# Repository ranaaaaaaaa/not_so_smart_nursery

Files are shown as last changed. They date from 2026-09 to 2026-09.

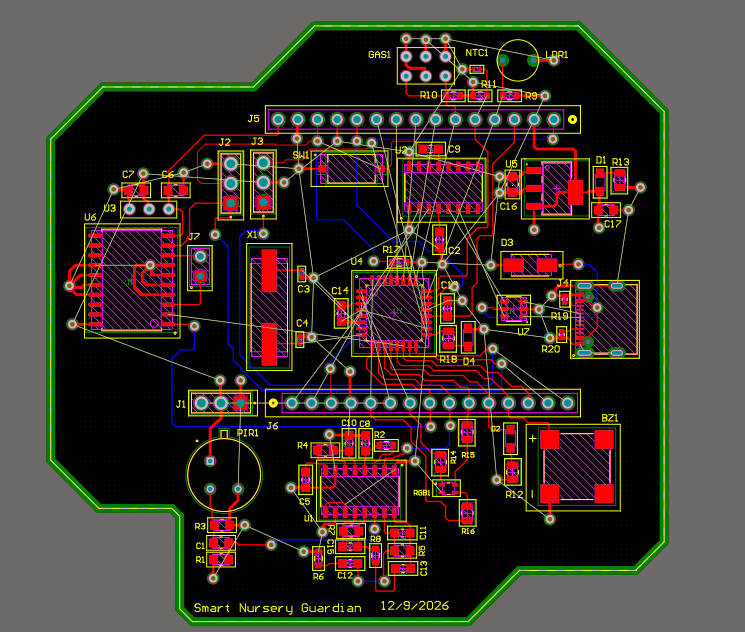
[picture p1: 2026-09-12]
Screenshot 2026-09-13 015350.png

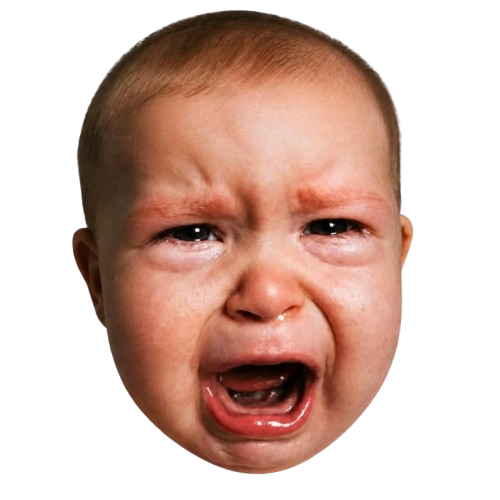
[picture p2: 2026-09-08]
3ayoota.png

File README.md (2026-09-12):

# not_so_smart_nursery

> drive:
https://drive.google.com/drive/folders/12p2iuLTkDaTgLdKXVU6b1ozY8I97_jF5

> tinkercad:[
https://www.tinkercad.com/things/jVpQvmCroje-copy-of-smart-nursery-guardian](https://www.tinkercad.com/things/jVpQvmCroje-copy-of-smart-nursery-guardian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)

# System Logic & Flow Overview

An AI-assisted embedded monitoring system that listens for infant cries, classifies their cause with a trained ML model, and coordinates a microcontroller to soothe, alert, and regulate the nursery environment in real time.

## 1. Architecture
The system is split across two devices that talk over a serial connection:

| Part | Runs On | Responsibility |
|---|---|---|
| **Python App (Tkinter GUI)** | Laptop | Microphone capture, noise reduction, VAD, ML cry classification, GUI display, video playback, Telegram alerts |
| **Firmware** | Microcontroller | Reads PIR, light (LDR), temperature (NTC), and gas sensors; drives servo, buzzer, RGB LED, lamp LED, and cooling fan; relays sensor events to the laptop |

**Key asymmetry:** audio never crosses the serial link - the laptop reads its own microphone directly, so cry detection and servo response have effectively zero latency. Every other sensor (motion, light, temperature, gas) is read by the microcontroller and relayed to the laptop over serial, so those messages are kept minimal to avoid flooding the link.

## 1.1 Servo Rocking Cycle (Actual Firmware Behavior)

While `cry == 1`, the servo repeats a fixed 4-second, 4-position cycle (not a simple back-and-forth between two angles):

| Time in cycle | Angle |
|---|---|
| 0–1s | 90° |
| 1–2s | 0° |
| 2–3s | 180° |
| 3–4s | 0° |

The cycle then restarts from 0°. As soon as `cry == 0`, the cycle timer resets and the servo stops advancing through positions.

## 2. Startup Sequence

1. **Microcontroller powers on** → initializes PIR, light, temperature, and gas sensors.
2. **Python app launches** → loads the pre-trained model (`already_trained_model.pkl`) once, opens the serial connection, and initializes the audio stream (PyAudio, 16 kHz, 1024-sample chunks).
3. **Tkinter GUI opens** in a calm/idle state and starts three independent polling loops via `window.after()`:
   - `update_gui` — reads serial data every 500 ms
   - `update_state` — evaluates `baby_state` every 500 ms and drives servo/video
   - `update_suggestion` — refreshes the on-screen suggestion text every 500 ms
   - The audio `read_stream` loop runs continuously (effectively every ~23 ms, gated by the mic buffer)

## 3. Live Audio Path (Cry Detection & Classification)

This is the core, time-critical loop and it runs on **two timescales at once**:

### 3.1 Fast path — every 1024-sample chunk (~64 ms), servo/VAD only
- Read a chunk from the mic.
- Normalize amplitude to `[-1, 1]`.
- If peak amplitude < 0.15 → treat as silence → **stop rocking** (`cry('C0')`).
- Otherwise → **start rocking** (`cry('C1')`) immediately.
- This gives the servo an instant reaction with no dependency on the ML model.

### 3.2 Slow path — every 6-second rolling window, ML classification
- Each chunk is also appended to a rolling buffer (`deque`, max 96,000 samples = 6 s @ 16 kHz).
- Once the buffer fills:
  1. Apply **spectral noise reduction** (`noisereduce`).
  2. Run **voice activity detection** via amplitude gating + `librosa.effects.split`.
  3. Extract a fixed-size feature vector: MFCC mean/std (13 coefficients each), F0 mean/std, RMS intensity mean/std, and duration.
  4. Feed the vector into the saved model → predicts `hungry`, `tired`, or `discomfort`.
  5. If the window was silent, `baby_state` resets to `"fine"`.
  6. The buffer then slides forward by 16,000 samples (1 second), so classification re-runs roughly once per second on overlapping windows.

```mermaid
flowchart TD
    A[Mic chunk arrives, 1024 samples] --> B{Peak amplitude < 0.15?}
    B -->|Yes| C[Send cry-stop to servo C0]
    B -->|No| D[Send cry-start to servo C1]
    C --> E[Push samples into 6s rolling buffer]
    D --> E
    E --> F{Buffer full<br/>96,000 samples?}
    F -->|No| G[Update waveform bars, wait next chunk]
    F -->|Yes| H[Noise reduction + VAD]
    H --> I{Sound present?}
    I -->|No| J[baby_state = fine]
    I -->|Yes| K[Extract MFCC / F0 / RMS / duration]
    K --> L[Run trained model]
    L --> M[baby_state = hungry / tired / discomfort]
    J --> N[Slide buffer forward 1s]
    M --> N
    N --> G
```

## 4. Response Logic by Classified State

Once `baby_state` is set, it drives GUI text, suggestions, servo/video, and buzzer via three independent 500ms loops:

| State | GUI Label | Suggestion | Extra Action |
|---|---|---|---|
| `hungry` | "YOUR BABY IS hungry" | "Consider feeding your baby." | Plays calming video **only if** gas level ≤ 500 (safe) |
| `tired` | "YOUR BABY IS tired" | "URGENT! Your baby requires your care right now." | Sends `B1` to buzzer over serial |
| `discomfort` | "YOUR BABY IS discomfort" | "Consider checking diaper, clothing, position." | — |
| `fine` | "YOUR BABY IS fine" | "NO suggestions." | Closes video window if open; sends `B0` (buzzer off) |

Note: the video and buzzer are **mutually exclusive with each other's triggers** — any state other than `hungry` closes the video window, and only `tired` keeps the buzzer active.

A **DISMISS** button lets a caregiver manually clear the displayed state to "fine" without waiting for the model.

## 5. Microcontroller-Side Sensor Logic

While the laptop handles audio, the microcontroller independently manages four sensor-driven behaviors every cycle:

### 5.1 Motion (PIR) → "Baby Awake"
- The PIR pin is sampled **once per second** (not continuously) within an 8-second window.
- Each `HIGH` reading increments a counter.
- If the counter reaches **4** before the 8 seconds elapse ⇒ `awake = 1`, and the window/counter reset immediately to start a fresh 8-second cycle.
- If 8 seconds elapse without reaching 4 ⇒ counter resets to 0 and `awake = 0` for that cycle.
- This means "4 motions in 8 seconds" is really "4 of up to 8 one-second samples," which filters out a single passing hand or a blanket shift while still catching sustained movement.
- Reported to the laptop over serial as `Awake:1` / `Awake:0`.

### 5.2 Room Lighting (LDR + LED)
The lamp LED turns on only when **both** are true:
- The LDR reading is **≥ 500** (this is the raw condition in firmware — confirm on your specific wiring/voltage-divider orientation whether a higher analog reading corresponds to a darker or brighter room, since LDR circuits can be wired either way), **AND**
- Baby is awake (from PIR) **OR** a cry is currently active (`cry == 1`, set by the laptop's fast VAD path over serial).

This is the one actuator that depends on **both** local sensor data and a laptop signal — everything else on the microcontroller (fan, status light) is fully local.

### 5.3 Temperature → Fan Speed + Status Color
| Range | Status Light | Fan |
|---|---|---|
| Below 25°C | Blue | Off (PWM 0) |
| 25°C – 30°C | Green | Half speed (PWM 127) |
| Above 30°C | Red | Full speed (PWM 255) |

Color and fan speed are derived from the same reading, so they always agree. Temperature is computed from the analog pin as `((analogRead * 5/1024) - 0.5) * 100` — a linear 10 mV/°C-with-0.5V-offset formula (common for analog temperature ICs; if you're actually using a raw NTC thermistor rather than a linear sensor, this formula would need to be replaced with a proper thermistor/Steinhart-Hart conversion, since NTC resistance isn't linear with temperature).

### 5.4 Gas/Smoke → Safety Alert (Highest Priority)
- Threshold: gas value **> 500**.
- **Buzzer logic on the microcontroller** is actually a combined OR: it sounds if gas exceeds the threshold, *or* if the laptop has sent `B1` (tired-cry alert) — either condition alone drives the buzzer HIGH. Both silence the buzzer via `B0`/gas dropping below threshold.
- The Python side additionally shows a full-screen red alert (`trigger_alert.py`) and plays an alert sound (`mashkal.mp3` via `playsound3`) and an image (`5atar.png`) when gas is detected.
- A **Telegram message** ("SERIOUS ALERT! CHECK ON YOUR BABY RIGHT NOW!") is sent via a direct HTTPS GET to the Telegram Bot API (`telegram_bot.py`).
- Any active calming video is immediately closed — the safety alert takes precedence.
- Alert window closes automatically once gas value drops back to ≤ 500.

```mermaid
flowchart TD
    G1[Gas reading] --> G2{Gas > 500?}
    G2 -->|Yes, alert not yet shown| G3[Trigger full-screen alert]
    G3 --> G4[Sound buzzer continuously]
    G4 --> G5[Send Telegram message]
    G5 --> G6[Close any active video]
    G2 -->|No, alert currently shown| G7[Close alert window]
    G2 -->|No change| G8[Do nothing]
```

## 6. Serial Message Summary

| Direction | Message | Purpose |
|---|---|---|
| MCU → Laptop | Temp, Gas, Awake, Fan, Light | Periodic sensor state, parsed each 500 ms poll |
| Laptop → MCU | `cry-detected` / `cry-ended` | Starts/stops servo rocking, feeds LED logic |
| Laptop → MCU | Servo start / stop | Direct rocking control (fast VAD path) |
| Laptop → MCU | `B1` / `B0` | Buzzer on (tired) / off |

## 7. Machine Learning Pipeline (Offline, Pre-Deployment)

This is the actual training pipeline (`training_libraries` script), which goes further than the design report's summary — it stacks **offline audio augmentation** with an **in-pipeline oversampler and feature selector**.

### 7.1 Data & Split
- **Data**: Donate-A-Cry Corpus (~457 labeled recordings) — heavily imbalanced toward "hungry."
- **Split**: 80/20 train/test **per class**, done before any augmentation (`train_test_split(test_size=0.20)`), then the training portion is further split 85/15 into train/validation (`test_size=0.15, stratify=Y_train`).

### 7.2 Offline Audio Augmentation (Training Data Only, Minority Classes Only)
For `discomfort` and `tired` (⚠️ **not** `hungry`, which is skipped entirely since it's already the majority class), each training clip is expanded with **10 augmentation techniques**, each applied at two "extreme" parameter values to maximize diversity:

| Technique | Parameter Range |
|---|---|
| White noise injection | factor 0.01–0.25 |
| Time stretch | rate 0.65×–1.45× |
| Pitch shift | ±5 semitones |
| Gain change | 0.4×–2.2× |
| Time shift (roll) | ±30% of clip length |
| Dynamic range compression | clip threshold 0.15–0.85 |
| Low-pass filter | cutoff 1200–4500 Hz |
| High-pass filter | cutoff 200–1500 Hz |
| Time masking | mask 5%–25% of clip |
| Frequency masking (band-stop) | 500–1500 Hz / 2000–4000 Hz |

Each augmented clip is saved to disk and run through the same feature extractor as the originals, so augmentation happens in the **audio domain**, not the feature domain.

### 7.3 Feature Extraction
For every clip (real or augmented): spectral noise reduction (`noisereduce`) → voice activity detection (`librosa.effects.split`) → a feature vector of MFCC mean/std (13 coefficients each), F0 mean/std, RMS intensity mean/std, and duration (~31 numbers per clip).

### 7.4 In-Pipeline Modeling (Second Layer of Imbalance Handling)
On top of the offline audio augmentation, the actual `sklearn`/`imblearn` pipeline adds:
1. **SMOTE** — synthetic oversampling in feature space (a second, independent imbalance fix layered on top of the audio-level augmentation).
2. **`SelectFromModel`** — a Random Forest picks the most important features and prunes the rest down to those above the mean importance (per code comments, this resolves a "46 → 20 features" mismatch between training and inference).
3. **`RandomForestClassifier`** — the final classifier.

Hyperparameters (`n_estimators`, `max_features`, `max_depth`, `min_samples_leaf`, `min_samples_split`) are tuned via `RandomizedSearchCV` (200 iterations, 3-fold stratified CV), optimizing multi-class ROC-AUC (one-vs-rest).

### 7.5 Evaluation
- Standard and per-class (multilabel) confusion matrices.
- Training vs. testing accuracy gap checked explicitly to flag over/underfitting (gap > 0.10 ⇒ overfitting; both scores < 0.60 ⇒ underfitting).
- Macro F1 < 0.5 is flagged as a sign the model may still be biased despite the imbalance corrections.

### 7.6 Deployment
The **entire fitted pipeline** (SMOTE + SelectFromModel + RandomForest) — not just the raw classifier — is pickled to `already_trained_model.pkl`. This matters: because feature selection is baked into the saved pipeline, the live GUI can feed it the full ~31-dimension raw feature vector and the pipeline handles the reduction internally, rather than the live code needing to replicate the selection step. The model is loaded once at Python app startup and never retrained live.

> **Note:** the standalone `get_live_features` helper inside the training script uses a silence threshold of `0.01`, while the deployed GUI's live audio path (`update_servo` / `get_live_features` in the Tkinter app) uses `0.15`. If you're troubleshooting sensitivity differences between training-time expectations and live behavior, this is one place to check.

## 7.7 Serial Framing Detail

Every command from the laptop to the microcontroller is terminated with `\r` (added in the `cry()` helper in `serialpython.py`), and the firmware reads with `Serial.readStringUntil('\r')`. Sensor data flows the other direction as a single comma-separated line (e.g. `Temp:26.30,Gas:180.00,Awake:1,Fan:1,Light:0`), parsed on the laptop by splitting on `,` then `:`.

## 7.8 Alert & Video Helper Windows

- **`trigger_alert(window)`**: opens a maximized (`zoomed`), always-on-top `Toplevel` window with a red background, alert text, a warning image, and plays an alert sound (non-blocking) — then calls `send_alert()` to fire the Telegram message and returns the window handle so the main loop can track/destroy it.
- **`play(window)`**: opens a `Toplevel` video window using `pyvidplayer2`, drawing frames onto a `Canvas` at roughly 30 fps via a self-scheduling `update()` loop, and cleans up the video and window together whether it finishes naturally or the user closes it.

## 8. Hardware Components

- Arduino Nano
- NTC thermistor (temperature)
- PIR motion sensor
- Photoresistor / LDR (light)
- Gas sensor
- Buzzer
- RGB LED (status) + standalone LED (room lamp)
- L293D motor driver + DC motor/fan
- Micro servo (crib rocking)
- 4-layer PCB (Altium)

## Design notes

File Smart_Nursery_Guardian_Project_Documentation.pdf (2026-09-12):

## Smart Nursery Guardian: Project Plan and Technical Documentation

Mind Cloud Summer Training - Team 1

September 12, 2026

## 1 Two-Week Project Execution Plan

The project lifecycle is structured into two systematic phases to ensure parallel progress across hardware prototyping, software design, and PCB layout.

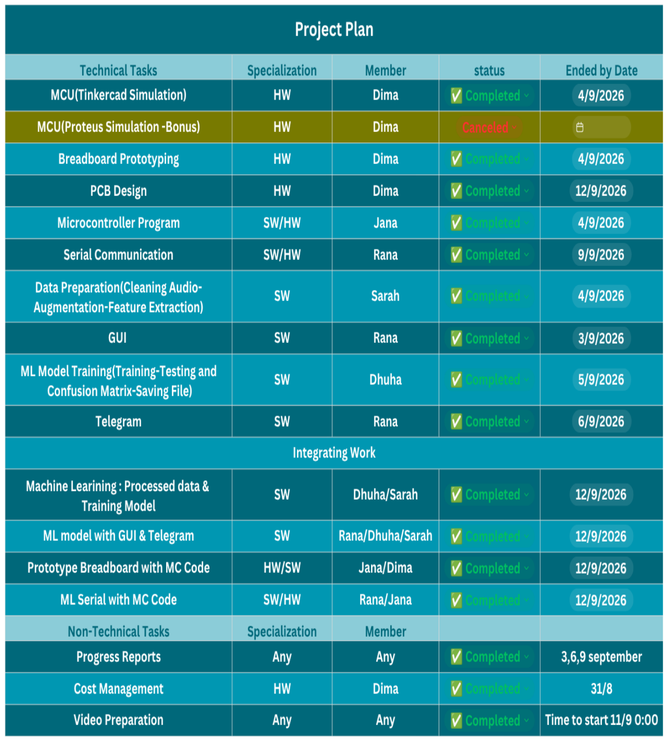
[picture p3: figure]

Project Plan

## 2 System Architecture and Technical Approach

The system relies on a hybrid architecture dividing tasks based on computational capability:

Laptop (Python):

Handles heavy audio processing, machine learning inference, GUI rendering, and Telegram cloud alerts.

Machine Learning Pipeline:

- Audio Processing Setups:Audio Processing Setup: Explored key audio processing libraries like librosa, scipy.signal, soundfile, and noisereduce to manipulate audio parameters and construct a comprehensive preprocessing pipeline.
- Augmentation and Split Strategy: Augmentation & Split Strategy: Split raw data (80% train / 20% test) before augmentation to prevent data leakage. Skipped the majority class (hungry) during augmentation to mitigate class imbalance, while expanding minority classes (discomfort, tired) using 10 techniques with 2 extreme-value boundaries per method.
- Feature Extraction Logic: Feature Extraction Logic: The extract_cry_features function removes background noise using spectral gating, trims silence/gasps via Voice Activity Detection (VAD) using librosa.effects.split, and returns None if no signal remains. Valid signals yield a 29-element feature vector (13 MFCC means/stds, F 0 mean/std, RMS intensity mean/std, and duration) saved as .npy files for model training. Pipeline Validation & Live Inference: Validated output quality by playing raw vs. augmented samples (sounddevice) and generating waveform comparison plots (plot_two_signals). Designed get_live_features and classify_live_record for real-time GUI integration (Rana’s code), filtering out silent audio (<0.01 amplitude) before passing live features to the saved pipeline. Severe Class Imbalance: The dataset was heavily biased toward hungry. Solution: Excluded hungry from augmentation while generating balanced synthetic samples for minority classes using 10 varied transformations. Audio Artifacts & Noise Ingestion: Silent recordings, gasps, and background noise corrupted feature metrics. Solution: Implemented noisereduce paired with VAD segmentation, automatically returning None for silent inputs.
- Training Stage: The training data is loaded and SMOTE is applied to handle class imbalance, followed by feature selection using a preliminary Random Forest model. A machine learning pipeline is then constructed and optimized using RandomizedSearchCV over a hyperparameter grid to find the best Random Forest classifier settings.
- Saving Trained Model: Upon completing the grid search and identifying the best estimator, the fully trained model is serialized and saved onto the hard disk as a Pickle file (.pkl). This enables the retrieval and reuse of the trained model for subsequent testing or live deployment without retraining.
- Testing and Assessment Stage: The saved model is loaded and evaluated on testing data to generate predictions, followed by performance assessment via Confusion Matrices and multilabel confusion matrices. Training and testing accuracy scores are calculated alongside Macro F1 and Weighted F1 metrics to check for overfitting and bias.
- Extracting Prediction as Outputs: A dedicated live classification function loads the saved model to process incoming audio feature inputs and generate model predictions. The numerical prediction is then mapped via the label map dictionary into a clear textual output representing the infant’s state.
- Preprocessing, Augmentation and Training Model Results:

– Optimization & CV Results: Randomized search yielded optimal parameters (n_estimators =
400, max_depth = 14, min_samples_split = 3, min_samples_leaf = 4, and max_features =′ sqrt′
) with a cross-validation score of 0.934.
– Performance Metrics: The model achieved 99.0% training and 81.8% testing accuracy (gap: 0.17), with a high weighted F1 of 0.82 contrasting a macro F1 of 0.51.

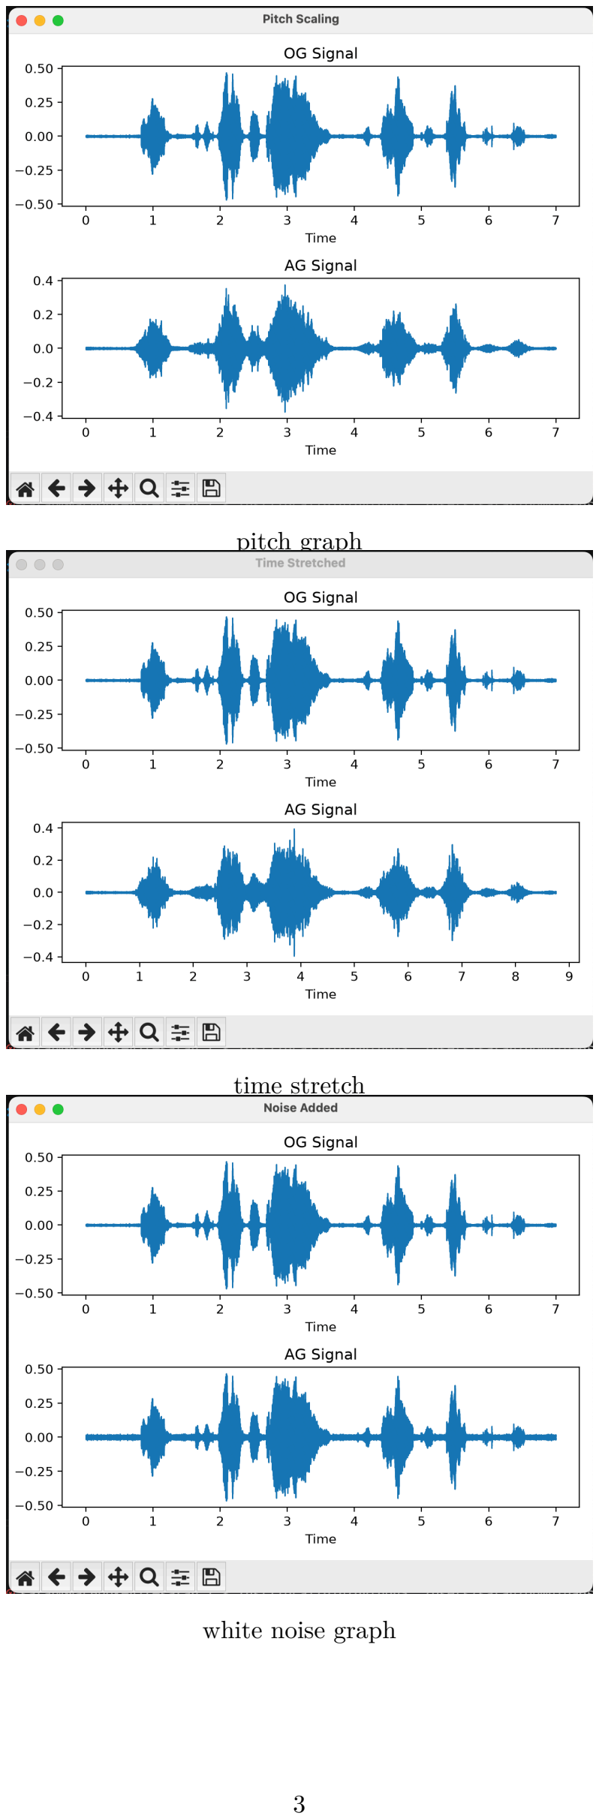
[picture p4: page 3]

pitch graph

time stretch

white noise graph

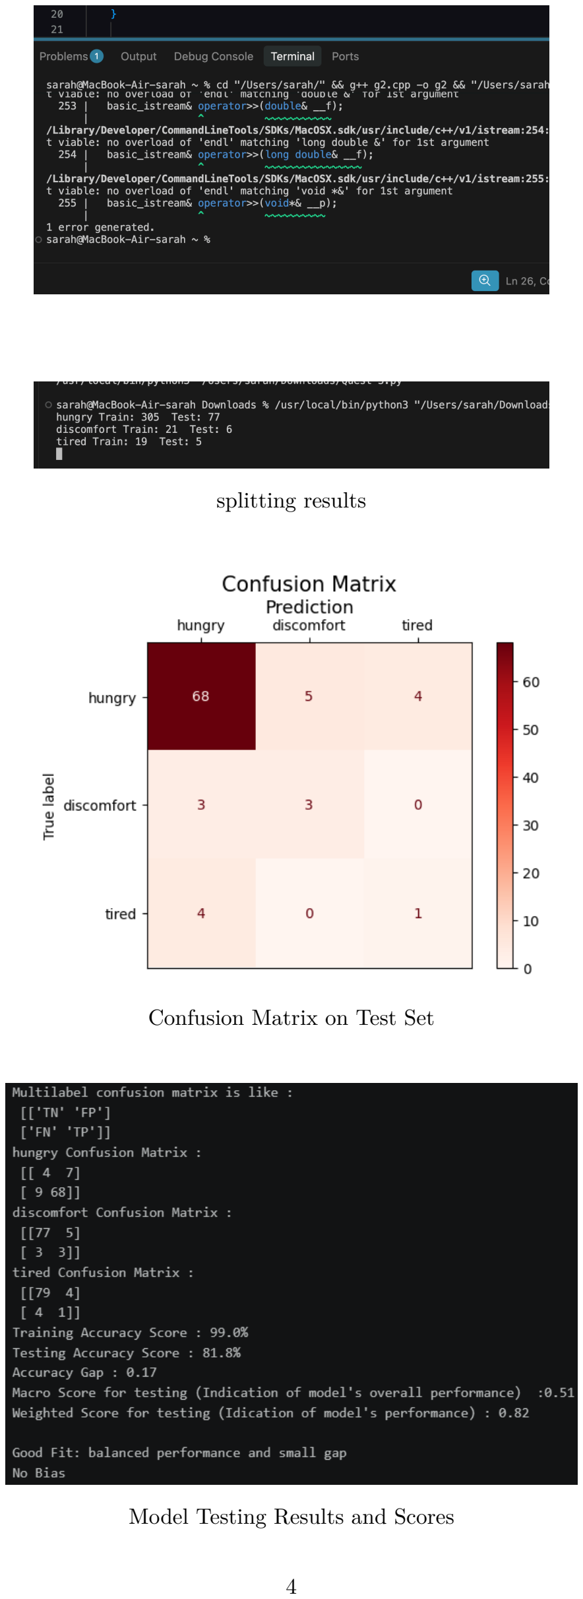
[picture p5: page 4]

splitting results

Confusion Matrix on Test Set

Model Testing Results and Scores

GUI Rendering:

- GUI Foundation: Started with GUI by laying the base skeleton for incorporating the serial and ML model into later, and added more features along the way.
- Audio Input Idea: First it was an idea to receive audio as an input internally without actually showing it on the GUI, but then it was decided that a simple GUI for sound that resembles a voice memo like that of mobile recording would benefit testing purposes and moms who want to make sure that the audio input is working. This was built using a live bar graph (matplotlib bars embedded in the Tkinter window via FigureCanvasTkAgg), fed by a PyAudio stream reading 1024-sample chunks and updating the amplitude levels continuously.
- Sensor Labels: Added the labels for the features that were supposed to receive their inputs from the hardware, such as fan, light, awake, gas, and temp values. Their values were randomized at first for testing purposes, and later set to a certain value to test triggering alerts and Telegram notifications. The baby state label was set and randomized as well.
- Clock: Then for aesthetic purposes and for practicality as well, a timer was added in the GUI to see the clock, updating every second through the ‘.after‘ method.
- Serial Connection: Then, after the microcontroller code was done, it was time for the serial connection, where the library pyserial was used. It was at first for just receiving the line for the readings, decoding it, then string manipulation to extract the data we need (Temp, Gas, Awake, Fan, Light, parsed from the raw line). Added a few lines to the microcontroller code for printing that line repeatedly, and suggested removing all loops and delays in order not to lag the serial data input through Python, and updating the data regularly through GUI.
- Telegram Bot: Then the Telegram bot was set using token and using JS protocol (JSON) requests and responses, triggered through ‘trigger_alert‘ when the gas value crossed the threshold.
- Incorporating the ML Model: After the ML code was done, it was time to incorporate it to the GUI. I faced an issue, which was that the audio input wasn’t really suitable for detecting the cries. When I first added the data input part, I reached a threading and queueing approach, then decided to instead replace it with a simpler approach, which was using an ‘.after‘ method. Instead of continuously inputting audio, input continuous little chunks of data input that is good enough for a simple voice memo logic, which didn’t quite align with detecting the cries at all. So I searched and found that I could add a rolling audio feature by adding a deque, holding a 6 second window (96000 samples at 16kHz) that slides forward by 1 second once full, and gets passed through ‘extract_cry_features‘ (noise reduction, VAD, MFCCs, pitch, RMS intensity, duration) before being classified by the saved model.
- Feature Additions Tied to ML Input: I then added servo stop/start feature in case of crying, running on every 64ms chunk through ‘update_servo‘ so the response is instant, separate from the 6 second window used for ML classification. Also added buzzer trigger when tired, and other features that depended on the ML input.
- Window Management Bug: After bringing the whole project together, I found that closing the unwanted windows after the baby state changed wasn’t handled, as when the baby was hungry, a video window was triggered on top of the main GUI, but if the baby state changed to tired before the video ended, the video resumed without interruption, which was wrong. So that was handled, the video window now gets destroyed and reset to None whenever the state moves to discomfort, tired, or fine.
- Priority Handling: Priorities, as well as the gas alert, dominated over the others, the gas alert window takes over and closes the video window if gas exceeds the threshold, even mid hungry state.
- Suggestion Label & Dismiss Button: Then I added a suggestion label in the end, updating every 500ms based on the current baby state, and a dismiss button, if the parent actually read the baby state label and found the baby to be, say, hungry, and just fed the baby, they could just dismiss the hungry so the baby state will again be fine.

- Known Issue: The ‘.after‘ method, used throughout the project (waveform updates, state checks, suggestion updates, serial polling, all running on their own recursive ‘.after‘ loops), was also updating the GUI continuously, which caused a bit of lag.

Microcontroller (Firmware):

Executes low-level, real-time sensor polling (motion, temperature, gas, light) and direct hardware actuation (fan, buzzer, servo motor).

- Firmware Scope: The firmware handled the local sensors and actuators while the laptop side handled cry detection and classification.
- Testing Environment: The cry and tired flags were treated as external inputs from the higher-level system, but the serial parsing that sets them was not part of this firmware work. The code was first tested in Tinkercad simulation and later tested on the physical hardware.
- Pin Configuration: The firmware configured the pins for the PIR sensor, LDR light sensor, gas sensor, temperature sensor, buzzer, RGB LED, room LED, motor driver, and servo. It treated the PIR sensor as a digital input, the LDR, gas, and temperature sensors as analog inputs, the buzzer and LEDs as digital outputs, the motor enable pin as a PWM output, and the servo as a servo-library output.
- Gas Safety: For gas and smoke safety, the gas sensor was read with analogRead and compared with a threshold. If gas exceeded the threshold, or if the tired flag was active, the buzzer was turned on. An else branch was added to turn the buzzer off again when the condition was no longer true.
- Temperature Control: For temperature control, the raw analog value was converted to voltage and then to Celsius. The RGB LED and cooling fan were controlled together: below 25 degrees the blue LED was on and the fan was off, from 25 to 30 degrees the green LED was on and the fan ran at half speed, and above 30 degrees the red LED was on and the fan ran at full speed. Motor direction was set with the IN1 and IN2 pins, and fan speed was set with analogWrite on the enable pin.
- Motion Detection: For motion detection, the PIR sensor was sampled every second inside an 8-second window. If four or more motions were detected in that window, the baby was considered awake. The timing used millis instead of delay so the rest of the firmware could keep running.
- Room Lighting: For room lighting, the LDR value was read with analogRead. The room LED turned on only when the room was dark and either the baby was awake or a cry was currently detected. An else branch turned the LED off again.
- Crib Rocking: For servo rocking, when cry was active the servo cycled through 0, 90, 180, and 90 degrees, holding each position for about one second. The timing used millis instead of delay, and the timing variable was reset when crying stopped.
- Challenges and Solutions: The main challenges were finding suitable thresholds for normal conditions, making sure the buzzer and LED turned off again after being triggered, deciding what should be analog and what should be digital, converting the temperature sensor reading to Celsius, and avoiding blocking loops and delay calls. Blocking code caused serial commands to be missed because the main loop could not run continuously. This was solved by replacing loops and delays with if conditions that run once per main loop, keeping state variables outside the loop, and using millis for timing. Another challenge was the real hardware LDR sensor, which read low values as light and high values as darkness, so the light condition was changed from less than the threshold to greater than the threshold compared with simulation.
- Code Implementation Details: Important code details include the use of millis and unsigned long for timing, explicit else branches for buzzer and LED off states, analogRead for LDR, gas, and temperature sensors, digitalRead for PIR, analogWrite for fan speed, the Servo library for crib rocking, the 8-second PIR window with 1-second sampling, the temperature-to-fan and LED mapping, the light logic based on darkness plus awake or cry, and servo cycling only while cry was active.

- Final Implementation: The firmware was successfully implemented in Tinkercad simulation and gave accurate results for all test cases for all sensors and conditions. After that, I helped test the physical hardware and debug its connection with the microcontroller code. I also helped with some component libraries in Altium and contributed to hardware testing and debugging.

Hardware:

- Prototype Breadboard and Simulation: Prototype Simulation and Physical Assembly The hardware development phase began with virtual prototyping to validate circuit logic before physical assembly. Initially, the system architecture was designed around an STM32 Black Pill using Proteus; however, persistent software crashes and simulation instability necessitated a pivot to an Arduino Nano. To ensure a reliable testing environment, the complete circuit was successfully modeled and verified in Tinkercad, utilizing the architecturally similar Arduino Uno as a functional stand-in for the simulation. Following this virtual verification, the physical prototype was constructed on a breadboard strictly according to the Tinkercad schematic. The transition from simulation to real-world hardware was seamless, with the physical assembly operating perfectly on the first iteration, thereby establishing a fully verified foundation for the subsequent custom PCB layout and routing phase.
- Custom PCB Design and Layout: The development of the custom Printed Circuit Board (PCB) required extensive research to transition from pre-assembled modules to discrete onboard components. Significant effort was dedicated to identifying specific manufacturer part numbers (MPNs) through LCSC, acquiring accurate component libraries, and defining the precise electrical connections for the Arduino Nano’s core architecture—including the ATmega microcontroller, crystal oscillator, USB-C interface, and reset circuitry—as well as the discrete elements of the voltage regulator and PIR sensor. Once the schematic document was successfully finalized, it was transitioned into the Altium Designer PCB layout environment, where strict component placement strategies were applied to ensure system stability. High-current connections for the DC and servo motors were deliberately isolated from sensitive logic components to prevent electrical noise and power surges from disrupting the microcontroller. Furthermore, the PIR sensor’s amplification circuitry was carefully positioned away from the center of the board to protect its highly sensitive resistor from potential interference, ensuring reliable signal integrity across the entire system.
Additionally, the transition from schematic capture to the physical PCB layout presented unforeseen technical challenges. Syncing the comprehensive schematic data into the PCB environment resulted in significant software instability, including severe system glitches and GPU crashes due to the heavy rendering requirements of the design software. Overcoming these hardware and software toolchain constraints required careful troubleshooting to successfully migrate the design data, ultimately allowing the critical routing phase to proceed without compromising the board’s integrity.

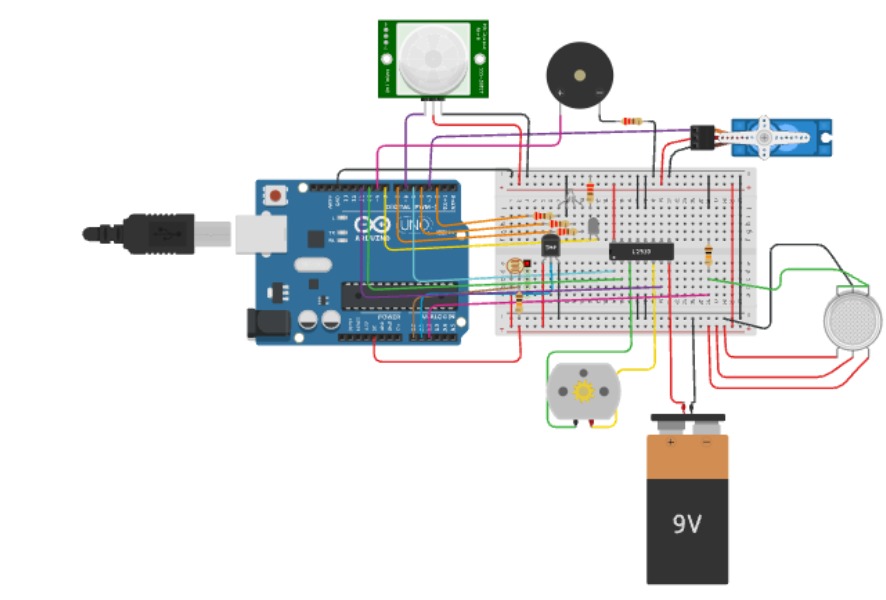
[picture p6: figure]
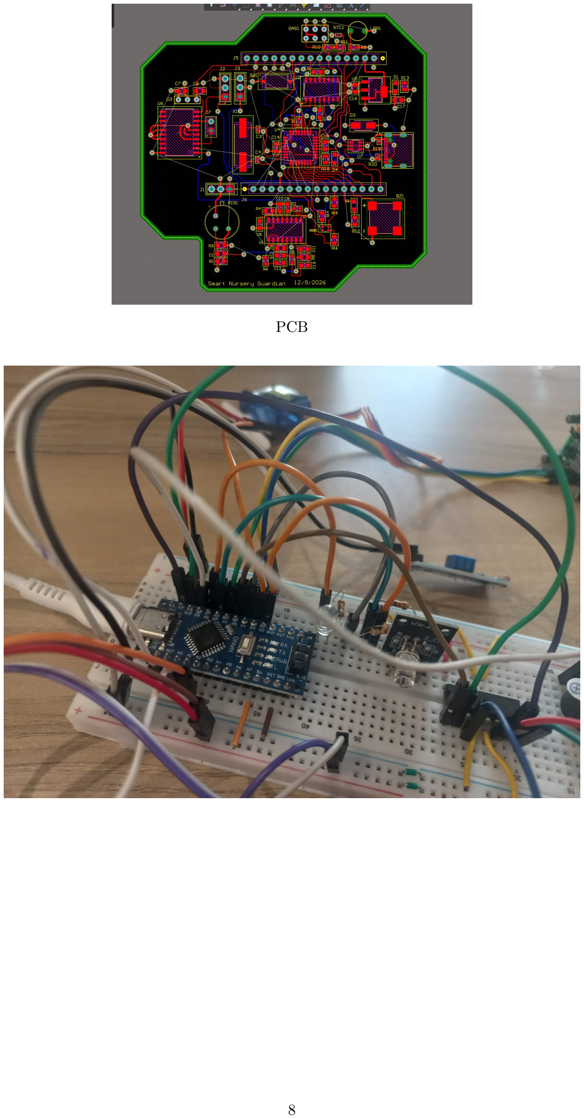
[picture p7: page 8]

PCB

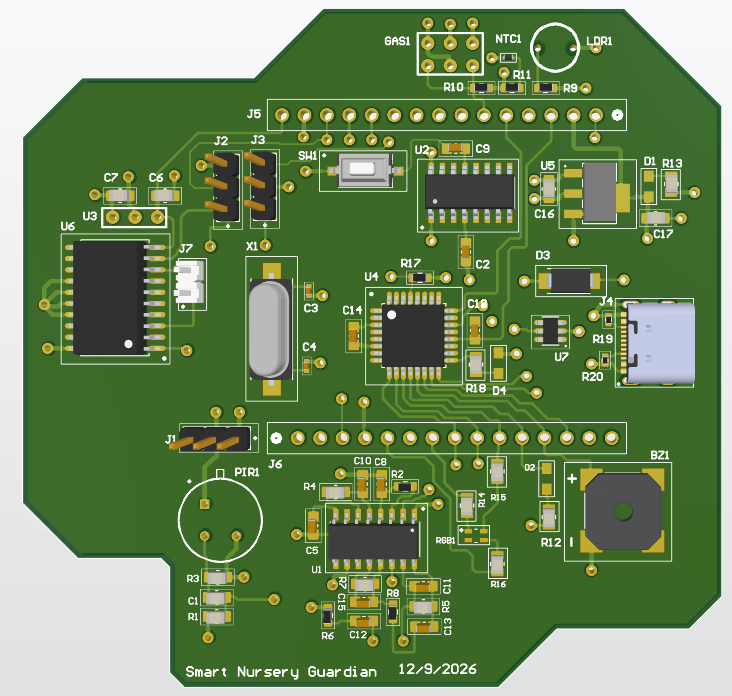
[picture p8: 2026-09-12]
Screenshot 2026-09-13 015406.png

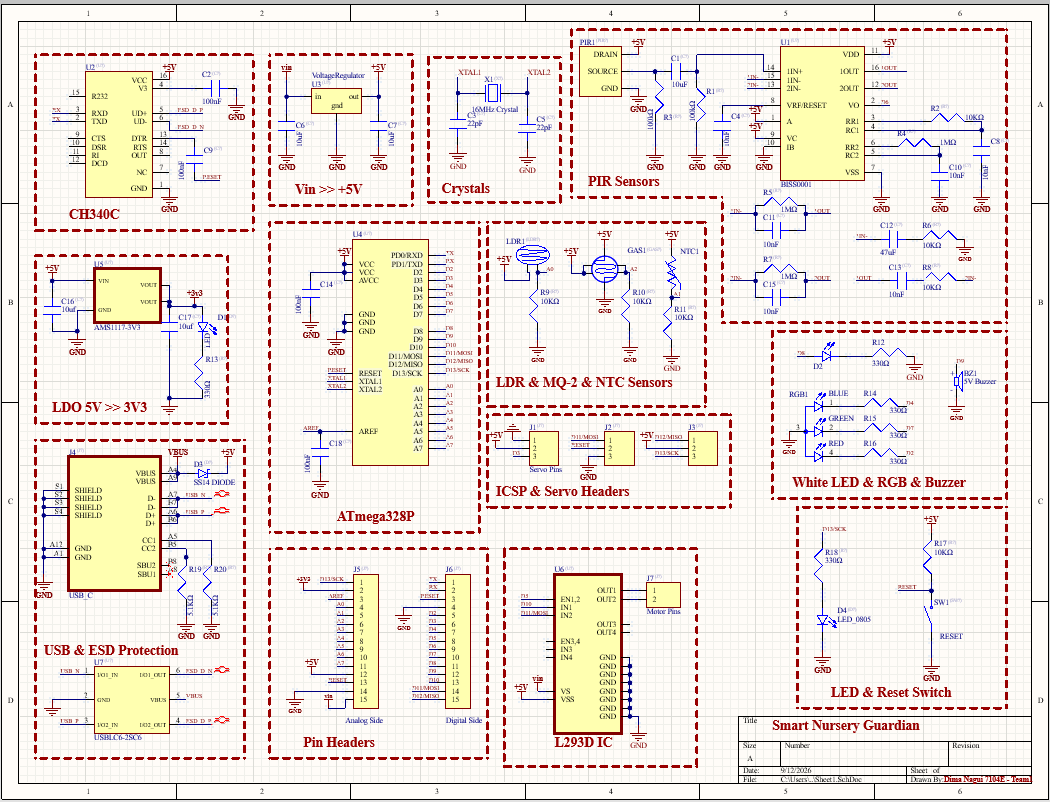
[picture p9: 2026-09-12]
Screenshot 2026-09-12 164814.png

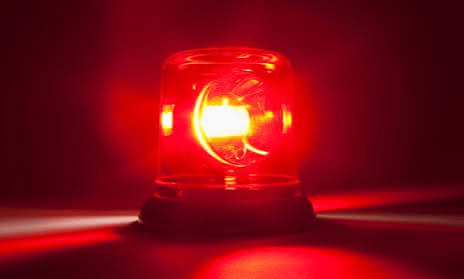
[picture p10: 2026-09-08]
5atar.png

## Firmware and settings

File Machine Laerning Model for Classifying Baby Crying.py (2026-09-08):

#Model's Training Libraries
import numpy as np
import pandas as pd
from sklearn.ensemble import RandomForestClassifier
from sklearn.metrics import accuracy_score,f1_score,confusion_matrix, classification_report,multilabel_confusion_matrix,ConfusionMatrixDisplay
import pickle
from imblearn.over_sampling import SMOTE
from sklearn.datasets import load_diabetes
from sklearn.linear_model import LinearRegression, Ridge, Lasso
from sklearn.metrics import mean_squared_error, r2_score
#Audio Procesing Libraries (Sarah)
import glob
import os
import shutil
from sklearn.model_selection import train_test_split
import soundfile as sf
import librosa
import matplotlib.pyplot as plt
import noisereduce as nr
import sounddevice as sd
import warnings
warnings.filterwarnings("ignore")
#*********************************************************************************************************************************#
#Stage 1 : Audio Preprocessing (By : Sarah Mustafa 7017E)
#Functions of Preprocessing stage
def add_white_noise(signal,noise_factor):
    noise= np.random.normal(0,signal.std(),signal.size)
    augmented_signal=signal + noise * noise_factor
    return augmented_signal
def time_stretch(signal,stretch_rate):
    return librosa.effects.time_stretch(y= signal,rate= stretch_rate)
def pitch_scale(signal,sr,n_steps): 
    return librosa.effects.pitch_shift(y=signal,sr=sr,n_steps=n_steps,bins_per_octave=12)
def extract_cry_features(signal, sr=16000):
    cleaned_signal = nr.reduce_noise(y=signal, sr=sr)
    intervals=librosa.effects.split(cleaned_signal,top_db=20)
    if len(intervals)>0:
        VAD_signal=np.concatenate([cleaned_signal[start:end]for start,end in intervals])
    else:
        VAD_signal=cleaned_signal
    if len(VAD_signal) == 0:
            return None
    MFCCs=librosa.feature.mfcc(y=VAD_signal,sr=sr,n_mfcc=13)
    MFCC_mean=np.mean(MFCCs,axis=1)
    MFCC_std=np.std(MFCCs,axis=1)
    f0=librosa.yin(VAD_signal,fmin=librosa.note_to_hz('C3'),fmax=librosa.note_to_hz('C7'),frame_length=2048)
    f0_clean=f0[~np.isnan(f0)]if f0 is not None else[]
    f0_mean=np.mean(f0_clean)if len(f0_clean)>0 else 0.0
    f0_std=np.std(f0_clean) if len (f0_clean)>0 else 0.0
    rms = librosa.feature.rms(y=VAD_signal)
    intensity_mean = np.mean(rms)
    intensity_std = np.std(rms)
    duration = librosa.get_duration(y=VAD_signal, sr=sr)
    feature_vector=np.hstack([
        MFCC_mean,
        MFCC_std,
        f0_mean,
        f0_std,
        intensity_mean,
        intensity_std,
        duration])
    return (feature_vector)
def plot_two_signals(signal,augmented_signal,sr,figure_name):
    fig,ax =plt.subplots(nrows=2,num= figure_name)
    librosa.display.waveshow(signal,sr=sr,ax=ax[0])
    ax[0].set(title="OG Signal")
    librosa.display.waveshow(augmented_signal,sr=sr,ax=ax[1])
    ax[1].set(title="AG Signal")
    plt.tight_layout()
    plt.show(block= False)
#----------------------------------------------------------------------------------------------------------------
#Loading and Splitting Raw Data set
RawData= r"D:\dhuha\Mind\donateacry_corpus" #add the data set file's path here
classes_labels=["hungry","discomfort","tired"]
label_map = {"hungry": 0, "discomfort": 1, "tired": 2}
X_train, Y_train = [], []
X_test, Y_test = [], []
noise_factors = [0.01, 0.05, 0.10, 0.15, 0.20]
stretch_rates = [0.75, 0.88, 1.0, 1.15, 1.35]
pitch_steps = [-4, -2, -1, 2, 4]
for cls in classes_labels:
    label = label_map[cls]
    files=glob.glob(f"{RawData}/{cls}/*.wav")
    train_files,test_files = train_test_split(files,test_size=0.20,random_state=40)
    os.makedirs(f"dataset_split/test/{cls}",exist_ok=True)
    os.makedirs(f"dataset_split/train/{cls}",exist_ok=True)
#Feature Extraction of audio data set
    for f in test_files:
        path_test=f"dataset_split/test/{cls}/{os.path.basename(f)}"
        shutil.copy(f, path_test)
        sig, sr_in = librosa.load(path_test, sr=16000, mono=True)
        feat = extract_cry_features(sig, sr=sr_in)
        if feat is not None:
            X_test.append(feat)
            Y_test.append(label)
    for f in train_files:
        path_train=f"dataset_split/train/{cls}/{os.path.basename(f)}"
        shutil.copy(f,path_train)
        sig, sr_in = librosa.load(path_train, sr=16000, mono=True)
        feat = extract_cry_features(sig, sr=sr_in)
        if feat is not None:
            X_train.append(feat)
            Y_train.append(label)                  
#Data Augmentation for minority classes (on training data set only)
    if cls=="hungry":
        continue
    else:
        os.makedirs(f"dataset_split/train_augmented/{cls}",exist_ok=True)
        for f in train_files:            
            signal , sr= librosa.load(f,sr=None)
            for idx, factor in enumerate(noise_factors):
                augmented_signal_N= add_white_noise(signal,factor)
                new_name_N= os.path.splitext(os.path.basename(f))[0]
                path_N=f"dataset_split/train_augmented/{cls}/{new_name_N}_noise_{idx}.wav"
                sf.write( path_N ,augmented_signal_N,sr)
                feat_N = extract_cry_features(augmented_signal_N, sr)
                if feat_N is not None:
                    X_train.append(feat_N)
                    Y_train.append(label)
            for idx, rate in enumerate(stretch_rates):
                augmented_signal_T= time_stretch(signal,rate)
                new_name_T= os.path.splitext(os.path.basename(f))[0]
                path_T=f"dataset_split/train_augmented/{cls}/{new_name_T}_stretch_{idx}.wav"
                sf.write(path_T,augmented_signal_T,sr)
                feat_T= extract_cry_features(augmented_signal_T, sr)
                if feat_T is not None:
                    X_train.append(feat_T)
                    Y_train.append(label)
            for idx, step in enumerate(pitch_steps):
                augmented_signal_P= pitch_scale(signal,sr,step)
                new_name_P= os.path.splitext(os.path.basename(f))[0]
                path_P=f"dataset_split/train_augmented/{cls}/{new_name_P}_pitch_{idx}.wav"
                sf.write(path_P,augmented_signal_P,sr)
                feat_P = extract_cry_features(augmented_signal_P, sr)
                if feat_P is not None:
                    X_train.append(feat_P)
                    Y_train.append(label) 
#saving processed data into extracted features folder                
os.makedirs("extracted_features", exist_ok=True)
np.save("extracted_features/X_train.npy", np.array(X_train))
np.save("extracted_features/Y_train.npy", np.array(Y_train))
np.save("extracted_features/X_test.npy", np.array(X_test))
np.save("extracted_features/Y_test.npy", np.array(Y_test))
#printing training and testing counts after augmentation
for cls in classes_labels:
    train_count = len(glob.glob(f"dataset_split/train/{cls}/*.wav"))
    test_count = len(glob.glob(f"dataset_split/test/{cls}/*.wav"))
    print(f"{cls} Train: {train_count}  Test: {test_count}")
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

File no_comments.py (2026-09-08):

from tkinter import *
import numpy as np
import random
from time import *

import pyaudio

from matplotlib.backends.backend_tkagg import FigureCanvasTkAgg
from matplotlib.figure import Figure

from video_player import play
from serialpython import *

MAX_AMPLITUDE = 4000
FIG_SIZE = (6, 2)

CHUNK_SIZE = 1024
SAMPLE_RATE = 44100
BAR_COUNT = 80

def create_waveform(window):
    wave_frame = Frame(
        window,
        width=700,
        height=300,
        bg="white"
    )

    wave_frame.pack(
        side=TOP,
        padx=3,
        pady=3
    )

    levels = np.zeros(BAR_COUNT)

    figure = Figure(figsize=FIG_SIZE)
    axis = figure.add_subplot(111)

    x_values = np.arange(BAR_COUNT)

    bars = axis.bar(
        x_values,
        levels,
        width=0.7
    )

    axis.set_ylim(0, MAX_AMPLITUDE)
    axis.set_xlim(-1, BAR_COUNT)
    axis.axis("off")

    figure.tight_layout()

    canvas = FigureCanvasTkAgg(
        figure,
        master=wave_frame
    )

    canvas.get_tk_widget().pack()

    audio = pyaudio.PyAudio()

    stream = audio.open(
        format=pyaudio.paInt16,
        channels=1,
        rate=SAMPLE_RATE,
        input=True,
        frames_per_buffer=CHUNK_SIZE
    )

    def check_audio():
        nonlocal levels

        data = stream.read(
            CHUNK_SIZE,
            exception_on_overflow=False
        )

        audio_array = np.frombuffer(
            data,
            dtype=np.int16
        )

        amplitude = float(
            np.mean(np.abs(audio_array))
        )

        levels = np.roll(levels, -1)
        levels[-1] = amplitude

        for bar, height in zip(bars, levels):
            bar.set_height(height)

        canvas.draw_idle()

        # stream.read() already waits for about 23 ms of audio
        window.after(1, check_audio)

    def close_waveform():
        stream.stop_stream()
        stream.close()
        audio.terminate()

    check_audio()

    return close_waveform


def update_gui(window, temp_label, gas_label, awake_label, fan_label, light_label):
    if ser.in_waiting > 0:  # only read if there's actually new data waiting
        raw_line = ser.readline().decode('utf-8', errors='ignore').strip()
        if raw_line:
            data = parse_line(raw_line)

            if "Temp" in data:
                temp_label.config(text=f"Temp: {data['Temp']} C")
            if "Gas" in data:
                gas_label.config(text=f"Gas: {data['Gas']}")
            if "Awake" in data:
                awake_text = "Yes" if data['Awake'] == "1" else "No"
                awake_label.config(text=f"Awake: {awake_text}")
            if "Fan" in data:
                fan_text = "ON" if data['Fan'] == "1" else "OFF"
                fan_label.config(text=f"Fan: {fan_text}")
            if "Light" in data:
                light_text = "ON" if data['Light'] == "1" else "OFF"
                light_label.config(text=f"Light: {light_text}")

    window.after(23, update_gui, window, temp_label, gas_label, awake_label, fan_label, light_label)

def main():
    window = Tk()
    window.title("Smart Nursery")
    window.config(bg="#d4f8ff", cursor="star")
    window_icon = PhotoImage(file="3ayoota.png")
    window.iconphoto(True, window_icon)
    ############ clock ############
    time_label = Label(window,
                       font=("ALGERIAN", 15, 'bold'),
                       fg="#78d4ff",
                       bg="white"
                       )
    time_label.pack(
        pady= 2
    )
    def update():
        time_string = strftime("%H:%M:%S %p")
        time_label.config(text=time_string)

        window.after(1000, update)
    update()
    ############ voice-memo waveform ############
    wave_label = Label(window,
                       text="LIVE AUDIO PROCESSING",
                       font=("ALGERIAN", 15, 'bold'),
                       fg='#b17ebf',
                       bg='white',
                       )
    wave_label.pack(
        side=TOP,
        pady= 2
    )
    close_waveform = create_waveform(window)

    def close_application():
        close_waveform()
        ser.close()
        window.destroy()

    window.protocol(
        "WM_DELETE_WINDOW",
        close_application
    )

    ############ SECTION1 ############
    SECTION1_label = Label(window,
                       text="ENVIRONMENT",
                       font=("ALGERIAN", 15, 'bold'),
                       fg='#b17ebf',
                        bg='white',
                       )
    SECTION1_label.pack(
        side= TOP,
    )
    ############ temp/gas/awake/fan/light ############
    temp_label = Label(window,
                       text="Temp: -- °C",
                       font=("ALGERIAN", 15, 'bold'),
                       fg='#78d4ff',
                       bg='white',
                       )
    temp_label.pack(side=TOP, pady=2)

    gas_label = Label(window,
                      text="Gas: --",
                      font=("ALGERIAN", 15, 'bold'),
                       fg='#78d4ff',
                       bg='white',
                      )
    gas_label.pack(side=TOP, pady=2)

    awake_label = Label(window,
                        text="Awake: --",
                        font=("ALGERIAN", 15, 'bold'),
                        fg='#78d4ff',
                        bg='white',
                        )
    awake_label.pack(side=TOP, pady=2)

    fan_label = Label(window,
                      text="☢FAN☢: --",
                      font=("ALGERIAN", 15, 'bold'),
                      fg='#78d4ff',
                      bg='white',
                      )
    fan_label.pack(side=TOP, pady=2)

    light_label = Label(window,
                        text="Light: --",
                        font=("ALGERIAN", 15, 'bold'),
                        fg='#78d4ff',
                        bg='white',
                        )
    light_label.pack(side=TOP, pady=2)

    update_gui(window, temp_label, gas_label, awake_label, fan_label, light_label)
    ############ SECTION2 ############
    SECTION2_label = Label(window,
                           text="Baby STATE",
                           font=("ALGERIAN", 15, 'bold'),
                           fg='#b17ebf',
                           bg='white',
                           )
    SECTION2_label.pack(
        side=TOP,
        pady= 2
    )
    ############ baby_state(randomized for now) ############
    LIST= ('HUNGRY','UNCOMFORTABLE','TIRED','FINE')
    baby_state= random.choice(LIST)
    # needs fixing
    # if baby_state == 'UNCOMFORTABLE' and data['Gas'] <= 500:
    #     play()
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
